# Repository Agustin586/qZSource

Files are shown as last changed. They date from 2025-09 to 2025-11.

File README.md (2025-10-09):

# ⚡ qZSource - Inversor Quasi Z-Source ⚡




## 🖼️ Vista del Proyecto

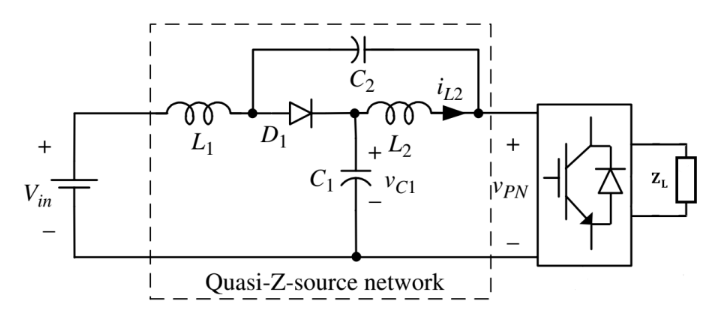
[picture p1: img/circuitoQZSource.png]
qZSource Inverter


> *Imagen del inversor Quasi Z-Source implementado*

## 📝 Descripción

Proyecto Final de Ingeniería Electrónica

Este proyecto implementa un **Inversor Quasi Z-Source (qZSI)** completo, incluyendo el diseño de hardware, firmware de control y simulaciones. El inversor qZSI es una topología avanzada que combina las funciones de elevación de tensión y inversión en una sola etapa, ofreciendo ventajas como inmunidad a cortocircuitos y mayor eficiencia.

## ⭐ Características Principales

- **Topología**: Quasi Z-Source Inverter
- **Control**: DSP TMS320F28335 de Texas Instruments
- **Tensión de entrada**: 300V DC (configurable)
- **Tensión de salida**: 300V AC pico (configurable)
- **Frecuencia de salida**: 50Hz senoidal
- **Protecciones**: Hardware y software configurables
- **Modos de operación**: Lazo abierto y cerrado

## 📁 Estructura del Proyecto

```
qZSource/
├── Esquematicos/          # Diseños de PCB y esquemáticos
├── Programa/              # Firmware para DSP TMS320F28335
├── Simulaciones/          # Modelos y simulaciones PLECS
└── README.md             # Este archivo
```

## 🛠️ Tecnologías Utilizadas

- **Hardware**: TMS320F28335 DSP, MOSFETs, Drivers de compuerta
- **Software**: Code Composer Studio, IQmath Library
- **Simulación**: PLECS Blockset, Matlab Simulink
- **Diseño PCB**: Altium Designer (presumiblemente)

## 👥 Autores del proyecto 2025
- **Fasolato, Alejandro**
- **Soso, Alvaro**
- **Zuliani, Agustin**

## 👥 Autores del proyecto 2024

- **Guido Cicconi**
- **Gustavo García** 
- **Juan Tinazzo**

## 📄 Licencia

Este proyecto está licenciado bajo la Licencia BSD de 3 Cláusulas. Ver los archivos de código fuente para más detalles.

## 📅 Año

> 2025 - Proyecto Final de Ingeniería Electrónica - Lazo de Control
> 
> 2024 - Proyecto Final de Ingeniería Electrónica - Proyecto Base

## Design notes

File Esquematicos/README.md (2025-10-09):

# 🔌 Esquemáticos - Hardware qZSI

Este directorio contiene todos los diseños de hardware para el Inversor Quasi Z-Source, incluyendo esquemáticos, layouts de PCB y documentación de diseño.

## 📦 Contenido

### 🧩 Módulos de Diseño

- **`ControlBoard/`**: 🧠 Placa de control principal con DSP TMS320F28335
- **`Design_AC_Output/`**: 🌊 Circuito de salida AC y filtros
- **`Design_DC_AC_Converter/`**: ⚡ Etapa inversora DC-AC principal
- **`Design_DC_Input/`**: 🔋 Circuito de entrada DC y red quasi Z-source
- **`Design_Drivers/`**: 🚗 Drivers de compuerta para MOSFETs
- **`Driver_MOSFET_DC_Input/`**: 🔌 Driver específico para MOSFETs de entrada
- **`MultiBoard/`**: 🏗️ Diseño integrado de múltiples placas
- **`Reformas/`**: 🔄 Modificaciones y actualizaciones del diseño

## 🏗️ Arquitectura del Hardware

### 🧠 Placa de Control (ControlBoard)
- **Procesador**: DSP TMS320F28335 de Texas Instruments
- **Interfaces**: 
  - 📊 Entradas analógicas para sensado de corriente y tensión
  - 🎛️ Salidas PWM para control de MOSFETs
  - 📡 Comunicación I2C para potenciómetros digitales
  - 🔍 Entradas digitales para protecciones
- **Alimentación**: 🔌 Fuentes aisladas para control y potencia

### ⚡ Etapa de Potencia

#### 🔋 Red Quasi Z-Source (Design_DC_Input)
- **Inductores**: 🧲 L1, L2 para almacenamiento de energía
- **Capacitores**: ⚡ C1, C2 para filtrado y elevación de tensión
- **Sensores**: 📏 Medición de corrientes y tensiones

#### 🔄 Puente Inversor (Design_DC_AC_Converter)
- **MOSFETs**: 🔌 Semiconductores de potencia para conmutación
- **Drivers**: 🚗 Circuitos de excitación aislados
- **Protecciones**: 🛡️ Detección de sobrecorriente y fallas

#### 🌊 Salida AC (Design_AC_Output)
- **Filtro**: 📊 Filtro LC para obtener forma de onda senoidal
- **Sensores**: 📏 Medición de tensión y corriente de salida
- **Protecciones**: 🛡️ Monitoreo de parámetros de salida

### 🚗 Drivers de Compuerta (Design_Drivers)
- **Aislamiento**: 🔒 Aislamiento galvánico entre control y potencia
- **Protecciones**: 
  - 🔍 Detección de desaturación (DESAT)
  - ⚡ Protección por sobrecorriente
  - 🌡️ Monitoreo de temperatura
- **Señalización**: 💡 LEDs indicadores y señales de estado

## 📊 Especificaciones Técnicas

### ⚡ Parámetros Eléctricos
- **Tensión de entrada**: 🔋 200-400V DC
- **Tensión de salida**: 🌊 220V AC RMS (311V pico)
- **Corriente máxima**: ⚡ Depende del diseño específico
- **Frecuencia de conmutación**: ⏱️ 10 kHz
- **Frecuencia de salida**: 🌊 50 Hz

### 🛡️ Protecciones Implementadas
- ⚡ Sobrecorriente en inductores L1, L2
- 🔋 Sobretensión en capacitores C1, C2
- 🌊 Sobrecorriente en la salida AC
- 🌡️ Protección térmica en drivers
- 🚨 Fallas de hardware (FAULT, READY, OC, OCP)

## 🛠️ Herramientas de Diseño

Los esquemáticos fueron diseñados utilizando herramientas profesionales de diseño de PCB (probablemente Altium Designer o similar).

## 🎯 Consideraciones de Diseño

### 🔒 Aislamiento
- 🔒 Aislamiento galvánico entre etapas de control y potencia
- 🚧 Barreras de aislamiento en drivers de compuerta
- 🔌 Fuentes de alimentación aisladas

### 📡 EMI/EMC
- 📐 Layout optimizado para minimizar interferencias
- 🌍 Planos de masa apropiados
- 🔍 Filtros de entrada y salida

### 🌡️ Térmico
- 🌡️ Disipadores para semiconductores de potencia
- 📊 Monitoreo de temperatura en puntos críticos
- 💨 Ventilación adecuada

## 🧩 Estructura Modular

El diseño está organizado de forma modular para facilitar:
- 🔬 Pruebas individuales de cada etapa
- 🔧 Mantenimiento y reparación
- 📈 Escalabilidad del sistema
- ♻️ Reutilización de módulos

## 📚 Documentación

Cada módulo incluye:
- 📋 Esquemáticos detallados
- 📊 Lista de materiales (BOM)
- 🔧 Consideraciones de montaje
- 🧪 Procedimientos de prueba

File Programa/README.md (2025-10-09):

# 💻 Programa - Firmware qZSI

Este directorio contiene el firmware completo para el control del Inversor Quasi Z-Source implementado en el DSP TMS320F28335 de Texas Instruments.

## 📦 Contenido

- **qZSI-Firmware/**: Proyecto completo de Code Composer Studio con todo el firmware del inversor

## 🏗️ Arquitectura del Firmware

El firmware está organizado en módulos funcionales para facilitar el mantenimiento y la escalabilidad:

### 🧠 Módulos Principales

#### `main.c` - Corazón del Sistema
- **Función principal**: Inicialización y loop principal del sistema
- **Configuración inicial**: Setup de todos los periféricos del DSP
- **Interrupciones**: Manejo de interrupciones de timer y ADC
- **Estado del sistema**: Control del estado global de la aplicación

#### `qZSI.c/h` - Motor de Control del Inversor
- **Algoritmos de control**: Implementación de los controladores PID
- **Cálculo de PWM**: Generación de ciclos de trabajo para MOSFETs
- **Protecciones**: Sistema de protecciones por software
- **Conversiones ADC**: Procesamiento de señales analógicas a valores físicos
- **Funciones clave**:
  - `qzsi_dcBusController()`: Control del bus DC con algoritmo no lineal
  - `qzsi_outputVoltageController()`: Control de tensión de salida con PID cascadeado
  - `qzsi_updatePWM()`: Actualización de registros PWM del DSP
  - `qzsi_getOpenLoop_d0()`: Cálculo de ciclo de trabajo en lazo abierto

#### `mefPrincipal.c/h` - Máquina de Estados Principal
- **Estados del sistema**: INICIO, RUN, FALLA, RESET_FALLA
- **Gestión de fallas**: Detección y manejo de condiciones de error
- **Secuencia de arranque**: Coordinación del arranque del sistema
- **Interfaz de usuario**: Manejo de botones y LEDs indicadores

#### `mefArranque.c/h` - Secuencia de Arranque Inteligente
- **Arranque progresivo**: Encendido suave del inversor
- **Carga de capacitores**: Precarga controlada de la red Z-source
- **Verificaciones**: Chequeos de seguridad antes del arranque
- **Transiciones**: Cambio gradual entre modos de operación

### 🔌 Drivers y Periféricos

- **`main.c`**: Función principal y configuración inicial del sistema
- **`qZSI.c/h`**: Algoritmos de control del inversor quasi Z-source
- **`mefPrincipal.c/h`**: Máquina de estados principal del sistema
- **`mefArranque.c/h`**: Máquina de estados de arranque secuencial

### Drivers y Periféricos

- **`Drivers/`**: Drivers para periféricos externos
  - `digitalPot.c/h`: Control de potenciómetros digitales MCP4461 vía I2C
  - `key.c/h`: Debounce y manejo de botones con detección de flancos
  - `LedIndicator.c/h`: Control de LEDs indicadores con códigos de error
  - `MCP4461.c/h`: Driver específico para potenciómetro digital de 4 canales

### ⚙️ Inicialización de Hardware

- **`Inits/`**: Módulos de inicialización críticos del DSP
  - `Adc.c/h`: ADC de 12 bits, 16 canales, conversión sincronizada con PWM
  - `EPwm.c/h`: 6 módulos PWM para control de MOSFETs y sincronización
  - `Gpio.c/h`: 88 pines GPIO para entradas/salidas digitales
  - `I2C.c/h`: Comunicación I2C a 400 kHz para potenciómetros
  - `SysCtrl.c/h`: PLL, relojes del sistema, configuración a 150MHz
  - `PieCtrl.c/h`: Controlador de interrupciones vectorizadas
  - `Watchdog.c/h`: Perro guardián para detección de bloqueos

### 🛠️ Utilidades y Algoritmos

- **`Utils/`**: Funciones auxiliares matemáticas
  - `ringBuffer.c/h`: Buffers circulares optimizados para filtros digitales IIR/FIR

## 🎯 Características Avanzadas del Control

### 🔄 Algoritmos de Control Implementados

1. **🔋 Control de Tensión DC Bus**: 
   - Algoritmo no lineal basado en modelo matemático
   - Controlador con ganancias variables según punto de operación
   - Compensación automática de variaciones de carga
   
2. **⚡ Control de Tensión de Salida**: 
   - PID cascadeado: tensión externa, corriente interna
   - Filtros digitales pasa-bajos para reducir ruido
   - Generación de referencia senoidal con tabla lookup
   
3. **🎛️ Generación PWM Avanzada**: 
   - 6 señales PWM sincronizadas
   - Tiempos muertos programables
   - Protección por hardware integrada
   
4. **🛡️ Sistema de Protecciones Multinivel**: 
   - Protecciones por hardware (instantáneas)
   - Protecciones por software (configurables)
   - Recuperación automática después de fallas

### ⚙️ Parámetros de Configuración Críticos

El archivo `inverterConfig.h` permite configurar múltiples aspectos:

#### 🎚️ Modos de Operación
- `SALIDA_SENOIDAL`: Habilita salida senoidal vs. continua
- `OUTPUT_VOLTAGE_CLOSED_LOOP`: Control en lazo cerrado de tensión
- `BUS_VOLTAGE_CLOSED_LOOP`: Control en lazo cerrado del bus DC

#### 🛡️ Sistemas de Protección
- `HARDWARE_PROTECTIONS`: Protecciones por hardware del DSP
- `SOFTWARE_PROTECTIONS`: Protecciones por software configurables

#### 📊 Referencias del Sistema
- `OPEN_LOOP_VIN`: Tensión de entrada nominal (300V)
- `DC_BUS_VOLTAGE_REFERENCE`: Tensión del bus DC objetivo (380V)
- `MAX_OUTPUT_VOLTAGE_REFERENCE`: Tensión de salida máxima (300V pico)

### 📚 Librerías Especializadas

- **🧮 IQmath**: Biblioteca de matemática de punto fijo de TI (Q15, Q24)
- **🎯 DSP2833x**: Drivers optimizados y definiciones para el DSP F28335
- **📋 Headers TI**: Archivos de cabecera estándar de Texas Instruments

## 🔧 Detalles Técnicos de Implementación

### ⏱️ Temporización y Sincronización

### 🔨 Herramientas Requeridas

El proyecto está configurado para **Code Composer Studio** y requiere:

1. **Code Composer Studio v6.0** o superior
2. **Compilador C2000** de Texas Instruments
3. **Biblioteca IQmath** instalada
4. **XDS100v2** o emulador compatible para debugging

### 📁 Configuración del Proyecto

#### 🎯 Target Configuration
- **Device**: TMS320F28335
- **Connection**: XDS100v2 USB Emulator
- **Gel Files**: Configuración de registros y memoria

#### 🔗 Linker Configuration
- **Flash**: Código de inicialización
- **RAM**: Código crítico de control
- **Sectores**: Optimizados para velocidad de ejecución

### 🏃‍♂️ Proceso de Build

```bash
# Compilación optimizada para velocidad
Optimization Level: -O2
# Punto fijo habilitado
IQmath Support: Enabled
# Debugging symbols
Debug Info: Full
```

## 🔍 Análisis de Rendimiento

### 📊 Uso de Memoria
- **Program Flash**: ~80KB de 256KB disponibles
- **Data RAM**: ~15KB de 34KB disponibles
- **Stack**: 1KB reservado para interrupciones

### ⚡ Timing Analysis
- **ISR de control**: ~25µs de ejecución
- **Conversión ADC**: ~2µs por canal
- **Cálculo PWM**: ~5µs para 6 canales
- **Margen disponible**: ~18µs por ciclo de control

## 🚀 Próximas Implementaciones

### 🎯 Mejoras Planificadas
- [ ] Control adaptativo de ganancia
- [ ] Estimador de parámetros en línea
- [ ] Comunicación CAN bus
- [ ] Interface gráfica de usuario
- [ ] Data logging en memoria externa

- **⏰ Frecuencia PWM**: 10 kHz (período de 100 µs)
- **📊 Frecuencia de muestreo ADC**: 20 kHz (2 muestras por período PWM)
- **🌊 Frecuencia de salida**: 50 Hz (senoidal de red)
- **🔄 Loop de control**: Ejecutado cada 50 µs (sincronizado con PWM)

### 🧠 Optimizaciones de Rendimiento

#### 💾 Gestión de Memoria
- **Código crítico en RAM**: Rutinas de control para máxima velocidad
- **Datos en SARAM**: Variables de control en memoria rápida
- **Stack optimizado**: Configurado para manejar interrupciones anidadas

#### ⚡ Optimizaciones de Código
- **IQmath**: Aritmética de punto fijo para cálculos rápidos
- **Inline functions**: Funciones críticas declaradas como inline
- **Loop unrolling**: Desenrollado de bucles en filtros digitales

### 🔍 Sistema de Debugging

#### 📊 Variables de Monitoreo
- Variables globales visibles en debugger
- Buffers de datos para análisis en tiempo real
- Contadores de rendimiento y estadísticas

#### 🚨 Códigos de Error
- Sistema de LEDs con códigos específicos
- Registro de fallas con timestamp
- Recuperación automática o manual según tipo de error

## 🛠️ Compilación y Desarrollo

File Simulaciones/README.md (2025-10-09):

# 📊 Simulaciones - Modelado qZSI

Este directorio contiene las simulaciones y modelos matemáticos del Inversor Quasi Z-Source desarrollados para validar el diseño y optimizar los algoritmos de control.

## 📦 Contenido

- **`simulacion/`**: 🔬 Modelos de simulación y archivos de proyecto
- **`licencia/`**: 📄 Archivos de licencia del software PLECS

## 🛠️ Herramienta de Simulación

### 📊 PLECS (Piecewise Linear Electrical Circuit Simulation)

- **Software**: 📊 PLECS Blockset para MATLAB/Simulink
- **Versión**: 🎓 Licencia estudiantil 2022
- **Fabricante**: 🏢 Plexim GmbH

### 📄 Archivos de Licencia

El directorio `licencia/` contiene:
- 📄 `license.lic`: Archivo de licencia PLECS
- 📋 `General_Terms_and_Conditions_Plexim_2018.pdf`: Términos y condiciones generales
- 🎓 `PLECS_Student_Licensing_Terms_and_Conditions_11_2022.pdf`: Términos específicos de licencia estudiantil

## 🔬 Modelos Implementados

### 🏗️ Modelo Completo del Sistema

El modelo de simulación incluye:

#### 🔋 Red Quasi Z-Source
- **Inductores L1, L2**: 🧲 Modelado con resistencias parásitas
- **Capacitores C1, C2**: ⚡ Modelado con ESR (resistencia serie equivalente)
- **Comportamiento dinámico**: 📊 Respuesta transitoria y en estado estacionario

#### 🔄 Puente Inversor
- **MOSFETs**: 🔌 Modelo de conmutación ideal con pérdidas configurables
- **Drivers**: 🚗 Retardos y limitaciones de slew rate
- **Dead-time**: ⏱️ Tiempo muerto entre conmutaciones

#### 🧠 Control Digital
- **DSP**: 💻 Modelado de los algoritmos de control implementados
- **PWM**: 🎛️ Generación de señales moduladas
- **ADC**: 📊 Muestreo y cuantización de señales analógicas

#### 🌊 Filtro de Salida
- **Filtro LC**: 📈 Filtrado de armónicos de conmutación
- **Carga**: 🔌 Diferentes tipos de carga (resistiva, RL, no lineal)

### 🎯 Algoritmos de Control Simulados

#### 🔓 Control de Lazo Abierto
- 🎚️ Cálculo de ciclo de trabajo `d0` para shoot-through
- 🎛️ Cálculo de ciclo de trabajo `d` para vector activo
- 🌊 Generación de referencia senoidal

#### 🔒 Control de Lazo Cerrado
- **PID de Corriente**: ⚡ Control de corriente de inductor
- **PID de Tensión**: 🌊 Control de tensión de salida
- **Filtros Digitales**: 📊 Filtros pasa-bajos para mediciones

### 🛡️ Protecciones Simuladas
- ⚡ Límites de corriente en inductores
- 🔋 Límites de tensión en capacitores
- 🌊 Protección por sobrecorriente de salida
- 🚨 Detección de fallas de hardware

## 📋 Casos de Estudio

### 🔬 Análisis Realizados

1. **🚀 Arranque del Sistema**
   - ⚡ Secuencia de encendido progresivo
   - 🔋 Carga de capacitores de la red Z
   - 📊 Establización de tensiones

2. **📈 Respuesta ante Escalones**
   - 🔌 Cambios en la carga
   - 🔋 Variaciones de tensión de entrada
   - 🎯 Cambios en referencias

3. **🔍 Análisis de Estabilidad**
   - 📊 Márgenes de fase y ganancia
   - 📈 Respuesta en frecuencia
   - 🛡️ Robustez del control

4. **⚡ Eficiencia Energética**
   - 🔄 Pérdidas de conmutación
   - 🔌 Pérdidas de conducción
   - 📊 Eficiencia total del sistema

### ✅ Validación de Diseño

Las simulaciones se utilizaron para:

- **🧮 Dimensionamiento de componentes**: L, C, MOSFETs
- **🎛️ Ajuste de controladores**: Parámetros PID
- **🛡️ Verificación de protecciones**: Umbrales y tiempos
- **📈 Optimización de rendimiento**: THD, eficiencia

## ⚙️ Parámetros de Simulación

### 📊 Condiciones Nominales
- **Tensión de entrada**: 🔋 300V DC
- **Tensión de salida**: 🌊 220V AC RMS
- **Frecuencia de salida**: 📊 50 Hz
- **Frecuencia de conmutación**: ⏱️ 10 kHz
- **Carga nominal**: 🔌 Resistiva, RL

### 🧲 Componentes de la Red Z
- **L1 = L2**: 🧲 3.2 mH
- **C1 = C2**: ⚡ 500 µF
- **Frecuencia de resonancia**: 🎯 Optimizada para la aplicación

## 📊 Resultados y Validación

### 📈 Métricas Evaluadas
- **THD (Total Harmonic Distortion)**: 📊 Distorsión armónica total < 5%
- **Eficiencia**: ⚡ > 90% en condiciones nominales
- **Regulación de tensión**: 📈 ±2% para variaciones de carga
- **Factor de potencia**: 🎯 > 0.95 con carga resistiva

### 🔬 Comparación con Resultados Experimentales
- ✅ Validación de formas de onda
- ⚡ Verificación de eficiencia
- 🛡️ Confirmación de estabilidad

## 💻 Software Requerido

Para ejecutar las simulaciones:
- 📊 MATLAB R2020b o superior
- 🔧 Simulink
- 📈 PLECS Blockset (licencia válida)
- 🧠 Conocimientos básicos de electrónica de potencia

## 📁 Archivos de Salida

Las simulaciones generan:
- 📊 Formas de onda de tensiones y corrientes
- 📈 Análisis espectral (FFT)
- ⚡ Gráficos de eficiencia
- 📋 Reportes de THD
- ✅ Datos para validación experimental

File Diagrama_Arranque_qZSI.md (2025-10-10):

# 🔄 Diagrama de Flujo - Arranque del Convertidor qZSI

## 📊 Flujo Principal de Arranque

```mermaid
graph TD
    A[🔌 POWER ON] --> B[⚙️ INICIALIZACIÓN SISTEMA]
    B --> C[🛡️ VERIFICACIÓN HARDWARE]
    C --> D{🔍 Hardware OK?}
    
    D -->|❌ NO| E[🚨 ESTADO FALLA]
    D -->|✅ SÍ| F[🚀 INICIO ARRANQUE]
    
    F --> G[⏱️ Esperar 5s]
    G --> H[🔌 SW_IN = 1<br/>Conectar entrada resistiva]
    
    H --> I[⏱️ Esperar 10s<br/>Carga suave capacitores]
    I --> J[⚡ VSEL = 1<br/>Entrada directa]
    
    J --> K[🔋 Habilitar salida]
    K --> L[📈 Aumentar VBUS<br/>Objetivo: 380V]
    
    L --> M{🎯 VBUS = 380V?}
    M -->|❌ NO| L
    M -->|✅ SÍ| N[✅ VBUS Enganchado]
    
    N --> O[⏱️ Esperar 5s]
    O --> P[🌊 Aumentar VO<br/>Objetivo: 300V]
    
    P --> Q{🎯 VO = 300V?}
    Q -->|❌ NO| P
    Q -->|✅ SÍ| R[✅ VO Enganchado]
    
    R --> S[⏱️ Esperar 5s]
    S --> T[🟢 FUNCIONAMIENTO NORMAL]
    
    E --> U[💡 LED Código Error]
    E --> V{🔧 Reset Manual?}
    V -->|❌ NO| E
    V -->|✅ SÍ| C
    
    T --> W{🚨 Falla?}
    W -->|❌ NO| T
    W -->|✅ SÍ| E
```

## 🏗️ Diagrama Detallado de Estados

```mermaid
stateDiagram-v2
    [*] --> POWER_ON : Sistema energizado
    
    POWER_ON --> INICIO : Inicialización hardware
    INICIO --> CLEAR_INICIAL : Timer 100ms
    
    CLEAR_INICIAL --> RUN : Hardware Ready
    CLEAR_INICIAL --> WAIT_HW_READY : Hardware NOT Ready
    
    RUN --> INICIO_ARRANQUE : Ejecutar MEF Arranque
    
    state RUN {
        INICIO_ARRANQUE --> SW_IN_RESISTIVO : 5s delay
        SW_IN_RESISTIVO --> AUMENTANDO_VBUS : 10s delay + VSEL=1
        AUMENTANDO_VBUS --> CONTROLADOR_VBUS_ENGANCHADO : VBUS = 380V
        CONTROLADOR_VBUS_ENGANCHADO --> AUMENTANDO_VO : 5s delay
        AUMENTANDO_VO --> CONTROLADOR_VO_ENGANCHADO : VO = 300V  
        CONTROLADOR_VO_ENGANCHADO --> RUN_NORMAL : 5s delay
        RUN_NORMAL --> RUN_NORMAL : Operación continua
    }
    
    RUN --> FALLA : Error detectado
    FALLA --> REST_FALLA : Button CLR_FAULT
    REST_FALLA --> WAIT_HW_READY : 100ms delay
    WAIT_HW_READY --> RUN : Hardware Ready
    
    FALLA --> FALLA : Sin acción usuario
```

## ⚙️ Secuencia de Señales de Control

```mermaid
gantt
    title Secuencia Temporal de Arranque qZSI
    dateFormat X
    axisFormat %s
    
    section Hardware Init
    Reset Drivers    :done, reset, 0, 100ms
    Enable Level Shifters :done, enable, 0, 100ms
    
    section Arranque Suave
    SW_IN = 0 (Resistivo)  :active, sw0, 0, 5000ms
    SW_IN = 1 (Directo)    :sw1, after sw0, 10000ms
    VSEL = 1 (Bypass)      :vsel, 5000ms, 10000ms
    
    section Control VBUS
    Habilitar Salida       :vo_enable, 15000ms, 100ms
    Rampa VBUS 0→380V      :vbus_ramp, after vo_enable, 3000ms
    VBUS Estabilizado      :vbus_stable, after vbus_ramp, 5000ms
    
    section Control VO
    Clear Vo Inicial       :vo_clear, after vbus_stable, 100ms
    Rampa VO 0→300V        :vo_ramp, after vo_clear, 2000ms
    VO Estabilizado        :vo_stable, after vo_ramp, 5000ms
    
    section Operación
    Funcionamiento Normal  :normal, after vo_stable, 10000ms
```

## 📋 Descripción de Cada Etapa

### 🔧 **1. INICIALIZACIÓN (0-100ms)**
- Reset de drivers de compuerta
- Habilitación de level shifters
- Configuración inicial de periféricos
- Verificación de protecciones hardware

### 🔌 **2. ENTRADA RESISTIVA (5s)**
- `SW_IN = 0`: Conexión a través de resistor limitador
- Carga controlada de capacitores de entrada
- Protección contra corrientes de irrupción

### ⚡ **3. ENTRADA DIRECTA (10s)**
- `SW_IN = 1`: Bypass del resistor limitador
- `VSEL = 1`: Conexión directa a fuente
- Estabilización de tensión de entrada

### 🔋 **4. CONTROL VBUS (Variable)**
- Habilitación de salida PWM
- Rampa gradual de VBUS: 0V → 380V
- Control de lazo abierto inicial
- Verificación de alcance de referencia

### 🌊 **5. CONTROL VO (Variable)**
- Liberación de restricción de Vo inicial
- Rampa gradual de VO: 0V → 300V
- Transición a control normal
- Verificación de alcance de referencia

### 🟢 **6. FUNCIONAMIENTO NORMAL**
- Control automático de VBUS y VO
- Monitoreo continuo de protecciones
- Operación estable del inversor

## 🛡️ Protecciones Durante el Arranque

### Hardware
- Trip Zone activo en todo momento
- Monitoreo de sobrecorriente instantáneo
- Protección térmica de drivers

### Software
- Verificación de límites de tensión/corriente
- Timeouts en cada etapa
- Recuperación automática ante fallas menores

## ⏱️ Tiempos Típicos de Arranque

| Etapa | Tiempo | Descripción |
|---|---|---|
| Inicialización | 100ms | Setup hardware |
| Entrada Resistiva | 5s | Carga suave |
| Entrada Directa | 10s | Estabilización |
| Rampa VBUS | 2-5s | Dependiente de carga |
| Rampa VO | 1-3s | Control progresivo |
| **TOTAL** | **~20s** | Arranque completo |

Este arranque gradual asegura que no haya transitorios bruscos que puedan dañar los componentes del sistema. 🚀

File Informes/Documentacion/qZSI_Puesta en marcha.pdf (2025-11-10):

# PUESTA EN MARCHA

# qZSI

2025

## Director: Vazquez Sieber, Andrés

## Autores:

Fasolato, Alejandro Claudio, Soso, Alvaro Francisco,
Zuliani, Agustín Marcelo,

## 1. Introduction

El inversor monofásico quasi-Z-source (qZSI) desarrollado en el marco del proyecto final de la carrera de Ingeniería Electrónica, a diferencia de un inversor convencional de fuente de tensión, la inclusión de la red quasi-Z permite elevar la tensión de bus a partir de una fuente de entrada reducida mediante la inserción controlada de intervalos de shoot-through. Esta característica le otorga un funcionamiento más versátil, aunque al mismo tiempo introduce riesgos de operación asociados a la presencia de tensiones elevadas, corrientes pulsantes y circuitos de protección que deben verificarse antes de cada ensayo.

Dada la complejidad del equipo, resulta imprescindible contar con un protocolo estandarizado de encendido, destinado a guiar paso a paso el proceso de energización y las verificaciones intermedias necesarias para garantizar seguridad de las personas, preservación del hardware y validez de las mediciones obtenidas.

## 2. Objetivo

El objetivo de este documento es establecer un procedimiento detallado y seguro para la puesta en marcha del inversor qZSI, abarcando desde la preparación previa hasta la energización progresiva y las verificaciones de funcionamiento. Este protocolo permitirá:

- Reducir riesgos de daño al equipo y al personal durante los ensayos.
- Asegurar que las condiciones de prueba sean reproducibles.
- Facilitar la puesta en marcha mediante protocolos y configuraciones rápidas.
- Validar que los módulos de protección, sensado y control operan correctamente antes de aplicar potencia nominal.

## 3. Tareas preliminares

## 3.1. Verificaciones sobre las placas

Continuidad de masas.
Continuidad entre conexiones. Valor de las tensiones de fuentes.

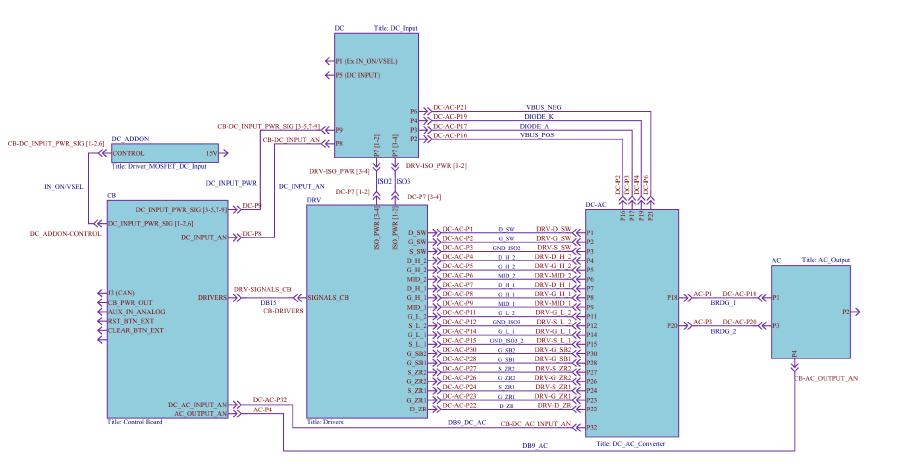
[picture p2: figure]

## 3.2. Conexionado externo

Conexión de la entrada CC del tablero a fuente de CC.
Conexión de la salida CA del convertidor al Tablero de Seguridad. Conexión del Tablero de Seguridad a la alimentación auxiliar. Conexión de salida CA del Tablero de Seguridad a la carga.

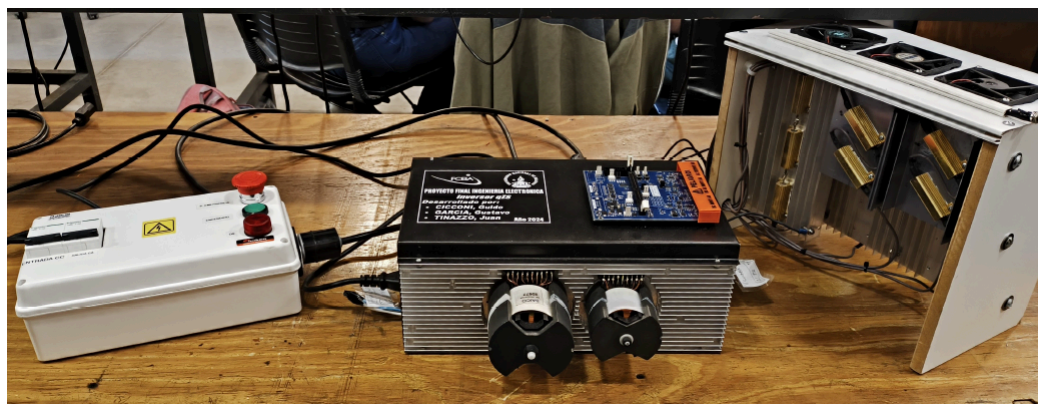
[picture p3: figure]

## 4. Firmware

## 4.1. Secuencia de arranque

4.1.1. Estados de la MEF
- RESET-INICIO: Inicialización de periféricos, colocar salidas en bajo.

Coloca la bandera de falla en cero.
PWM deshabilitado, inhabilita etapa entrada a drivers.
Limpia flag del flip flop de protecciones.
Habilita la salida de los level shifters.
Verificar que los drivers estén apagados con sus respectivas salidas.

TRANSICIONES

➔ Se detecta algún fault activo (UV, OV, OCP, emergencia) >> FAULT ➔ Aguarda 100ms, y si fault inactivo >> CLEAR

- CLEAR_INICIAL: Resetea drivers y flip flop.

Lee falla del driver.
Lee falla en sensor de corriente AC de efecto Hall. Lee falla de hardware del GPIO.

MEDICIONES

❖ De existir errores, puede medirse sobre la placa con un multímetro los distintos estados de reset y fallas antes mencionados.

TRANSICIONES

➔ Error de inicialización, lectura inválida o tensión fuera de rango.>> FAULT
➔ Si no hay falla, todos los periféricos fueron inicializados correctamente y la calibración del ADC fue completada >> INICIO - ARRANQUE

- INICIO_ARRANQUE: Se prepara para la carga del bus.

Se colocan banderas V0 y VB de arranque. Asegura MOS de la entrada abierto. Secuencia ‘1’ de Leds.
LED 2 = 0
LED 3 = 0
LED 4 = 1
Coloca las referencias de V0 y VB en 0.

MEDICIONES

❖ Medir que la tensión VBUS = 0 (durante 5 seg).

TRANSICIONES

➔ Transcurridos 5 segundos >> CARGA

- SW_IN_RESISTIVO: Carga de la red Z durante 10s.

Se habilita “resistencia” de precarga para cargar capacitores del bus lentamente.
- Si VBUS no sube, posible corto en bus o snubber → cortar y medir resistencia en bus.
Secuencia ‘2’ de Leds.
LED 2 = 0
LED 3 = 1
LED 4 = 0

MEDICIONES

❖ Medir VGS del Mosfet para ver la variación de su tensión.
❖ Medir la VBUS para observar su aumento y corroborar con los datos de la simulación.
❖ Medir forma de corriente de IL1 + IL2, Io. Corroborar con la simulación.

TRANSICIONES

➔ Activación de protección por hardware (OCP, OV, UV). >> FAULT ➔ Tiempo de precarga 10 segundos transcurrido >> AUMENTA VB

- AUMENTANDO_VBUS: Transición a LA desde Vin a Vb*.

MOSFET de entrada se polariza como llave cerrada.
Enciende salida senoidal con D máx = 0,45.
Setea referencia de VBUS y coloca d0 a lazo abierto, esperando que VBUS incremente.
Secuencia ‘3’ de LEDs.
LED 2 = 0
LED 3 = 1
LED 4 = 1

MEDICIONES

❖ VBUS
❖ Corrientes
- IL1 + IL2
- Io

TRANSICIONES

➔ Activación de protección por hardware (OCP, OV, UV). >> FAULT
➔ Elevación de Vb=Vb* >> CONTROL VB ONLINE
- CONTROLADOR_VBUS_ENGANCHADO: Valor de d0 comandado por Control.

Baja la bandera de Vb arranque, logrando así enganchar el control de tensión de bus. Se comenzará a utilizar d0 proveniente del algoritmo de control.
Secuencia ‘4’ de Leds:
LED 2 = 1
LED 3 = 0
LED 4 = 0

Durante este tiempo valen las siguientes funciones para calcular los ciclos de trabajo:
- d0 = (VBUS - Vin) / (2*VBUS)
- D = Vo/VBUS * sin(wt)

MEDICIONES

❖ VBUS

TRANSICIONES

➔ Activación de protección por hardware (OCP, OV, UV). >> FAULT ➔ Tiempo de enganche de 5 segundos >> CONTROL VB ONLINE VB

- AUMENTA_V0: Transición a LA desde Vo_inicial a Vo*

Setea V0* y coloca un D a lazo abierto, esperando que V0 incremente. Secuencia ‘5’ de Leds:
LED 2 = 1
LED 3 = 1
LED 4 = 0

MEDICIONES

❖ Vout

TRANSICIONES

➔ Activación de protección por hardware (OCP, OV, UV). >> FAULT
➔ Elevación de V0=V0* >> CONTROL V0 ONLINE
- CONTROLADOR_V0_ENGANCHADO: Valor de D comandado por Control.

Baja la bandera de V0 arranque, logrando así enganchar el control de tensión de salida. Se comenzará a utilizar D proveniente del algoritmo de control. arranqueV0 = 0 → D se controla por el Lazo cerrado/abierto

MEDICIONES

❖ Vout

TRANSICIONES

➔ Activación de protección por hardware (OCP, OV, UV). >> FAULT ➔ Tiempo de enganche de 5 segundos >> RUN

- RUN

LED de estado en RUN.

- Si VBUS se dispara, puede deberse a su controlador saturado. Además: Posible desconexión de la carga.
- Si la corriente de entrada es anómala, revisar inductores/cargas.

TRANSICIONES

➔ Se detecta OCP, OV, UV, sobretemperatura o error de firmware. >> FAULT ➔ Se recibe comando de parada o fin de ensayo. >> INICIO

- FAULT: Aislar el inversor, guardar log de error y esperar intervención.

Setea bandera de falla.
Requiere reset manual. Borra la bandera de falla, reinicia periféricos LED estado falla.

MEDICIONES

❖ Flip Flop seteado

TRANSICIONES

➔ Se ejecuta reset manual >> RESET FALLA

### Condiciones que disparan FAULT

➔ Protección por hardware activada:
◆ | OCP: corriente > umbral de comparador analógico.
◆ | OVP: tensión de bus o snubber > límite.
◆ | UVP: tensión de alimentación fuera de rango.
◆ | OTP: sobretemperatura en drivers o control.
➔ Comando manual (pulsador de emergencia).
➔ Error de firmware detectado (ADC out-of-range, ISR colgada, watchdog).

- RES FALLA

Apaga la etapa de entrada de los drivers.

TRANSICIONES

➔ Tiempo de apagado 100ms >> WAIT HW READY.

- WAIT HW READY

Reseta drivers y sensor efecto hall.
Resetea tripzone.
Baja la bandera de falla.

MEDICIONES

❖ Drv reseteados
❖ Tripzone reseteado

TRANSICIONES

➔ Hardware ready >> INICIO ARRANQUE.

## 4.2. Configuraciones FIRMWARE

4.2.1. Archivo inverterConfig.h

En este archivo se puede configurar el funcionamiento general del inversor, activando o desactivando distintos bloques que lo componen, y seteando las tensiones de referencia deseadas.Las macros disponibles son:

- SALIDA_SENOIDAL: si vale 1, la salida del inversor será senoidal, en caso contrario, será una tensión continua. Es una macro útil para testear el funcionamiento en las etapas iniciales.
- HARDWARE_PROTECTIONS: si vale 1, las protecciones por hardware del inversor están activadas, en caso contrario, estarán desactivadas. Es útil si por alguna razón se producen disparos espurios de las protecciones por hardware y se quiere investigar su origen.
- SOFTWARE_PROTECTIONS: análoga a la anterior, permite activar o desactivar las protecciones por software del inversor.
- OUTPUT_VOLTAGE_CLOSED_LOOP: si vale 1, la tensión senoidal de salida del inversor funciona a lazo cerrado, en caso contrario, a lazo abierto. Es útil a la hora de probar el funcionamiento del controlador de salida implementado.
- BUS_VOLTAGE_CLOSED_LOOP: análoga a la anterior, permite activar o desactivar el lazo de control de la tensión del bus de CC.
- OPEN_LOOP_VIN: es el valor de la tensión de entrada al momento del arranque del inversor, ya que se utiliza para generar la tensión del bus de CC a lazo abierto.
- DC_BUS_VOLTAGE_REFERENCE: es el valor de referencia deseado para la tensión del bus de CC.
- MAX_OUTPUT_VOLTAGE_REFERENCE: es el valor de referencia deseado para la tensión de salida del inversor, siendo este el valor de pico y no el RMS

4.2.2. Archivo qZSI.h

En este archivo se puede configurar el comportamiento dinámico, la tensión de salida inicial en el arranque y los valores de protección por software del inversor. Las macros disponibles son:

- STEP_TIME_MS: es el tiempo de delay deseado entre pasos de un setpoint, ya que todo cambio de setpoint se realiza de forma gradual, de a una unidad cada STEP_TIME_MS milisegundos. Por ejemplo, si STEP_TIME_MS = 50, el set-point deseado del bus de CC está seteado en 100V y el mismo se cambia a 200V, este irá incrementando de a 1V cada 50ms, llegando a 200V en 5s. En caso de requerir que la rampa de subida sea más rápida, se puede reducir el tiempo del escalón, pero el aumento de tensión seguirá siendo siempre de 1V por paso.
- INITIAL_D: es el valor deseado del ciclo de trabajo máximo del vector activo presente en la etapa 3 de la secuencia de arranque descrita anteriormente.
- DC_BUS_XI: es el valor de la constante de amortiguamiento ξ del sistema de segundo orden formado por la red Z y el controlador del bus de CC.
- DC_BUS_WN: es el valor de la frecuencia natural ωn del sistema de segundo orden formado por la red Z y el controlador del bus de CC. Estas últimas dos macros permiten configurar el comportamiento dinámico de la tensión del bus de CC.
- MAX_IL1, MIN_IL1, MAX_Iin, MAX_VC1, MAX_Vac, MAX_Iac, MIN_Iac: son los valores de umbral de las protecciones por software. Si la respectiva variable medida supera a sus valores de umbral, se activará la protección por software (en caso de que esté habilitada).
4.2.3. Archivo digitalPot.h

Mediante las macros VREF_IACm, VREF_IACp, VREF_VC12, VREF_Iin, VREF_IL1m, VREF_IL1p, VREF_IBRDGm, VREF_IBRDGp es posible configurar las tensiones de referencia utilizadas en los comparadores que accionan las protecciones por hardware. Gracias a la utilización de potenciómetros digitales, que se comunican con el DSP mediante el protocolo I2C, es posible configurar en el firmware los valores de referencia para la comparación. Estas macros mencionadas deben ser iguales al valor de tensión de referencia (en Voltios) deseado para cada caso. Al inicio del programa, se configuran los potenciómetros a partir de los valores seteados en estas macros. Aquellas macros cuyos nombres difieran en la última letra, siendo esta p o m, configuran la tensión de referencia para la misma señal, pero en el caso de p es la tensión de umbral máxima y en el de m, la tensión de umbral mínima.

## 5. Configuraciones externas

## 5.1. Fuente

Encadenar los canales de la fuente y encender la fuente Configurar las tensiones de salida …
Configurar la limitación de corriente
Medir en bornes la tensión y verificar que coincida con la deseada.

## 5.2. Carga

Ajustar o interconectar la carga en el valor deseado.
Medir en bornes y verificar el valor.
Si se utilizará escalón de carga, configurar el generador de onda para realizar la conmutación el rele y verificar el correcto funcionamiento.

## 5.3. Instrumental

5.3.1. Osciloscopio

Encender el equipo y ajustar los canales en el rango de medición esperado
Configurar cursores…
Configurar….
Verificar los canales y sus configuraciones con un generador de onda
5.3.2. Sondas diferenciales

Alimentar las sondas y configurar para la medición deseada verificar sus canales con el generador de onda.

5.3.3. Multimetro

Ajustar al rango y tipo de medición deseada.

## 6. Protocolo de encendido

## 6.1. Configuraciones

Configurar los instrumentos de medición, fuentes y cargas de manera adecuada, según lo requerido por el ensayo.

Verificar que la fuente de alimentación programable funcione correctamente; medir en vacío con multímetro que entregue la tensión seteada. Y limitación de corriente activada.
Conectar el banco RC a la salida de la fuente para suavizar la corriente de entrada. Revisar que las térmicas estén abiertas y que el pulsador de emergencia (“golpe de puño”) no esté accionado.
Medir la resistencia de carga y comprobar que coincide con el valor esperado.
Montar la protección plástica sobre la placa de control para evitar contacto con alta tensión.

## 6.1.1. Configuración de firmware

Programar el DSP C2000 con el código de control.
Verificar configuración inicial de PWM y ADC (sin aplicar tensión de potencia). Verificar que el firmware a cargar en el DSP sea el correcto, y que todos los parámetros sean acordes a lo configurado en el instrumental.
Verificar además la conexión entre la Control Board y la Docking Station.
Poner las variables que necesitamos ver en el código para ver que funcione como corresponde y ver la evolución.

## 6.2. Conexiones seguras

Realizar y verificar que todas las conexiones eléctricas sean correctas de acuerdo al ensayo a realizar.

Conexión de la entrada CC a fuente de CC.
Conexión de la salida CA del convertidor al Tablero de Seguridad.
Conexión del Tablero de Seguridad a la alimentación auxiliar.
Conexión de salida CA del Tablero de Seguridad a la carga.
Colocar las sondas de osciloscopio en los puntos de medición definidos y configurar escalas adecuadas.

Verificar que no haya cables sueltos.
Acomodarse en los puestos designados:

En caso de ser dos personas: una será la encargada de la alimentación del inversor y de tomar nota, mientras que otra realizará la carga del código y manejará el osciloscopio.
En caso de ser tres personas: una será la encargada de la alimentación del inversor,otra tomará nota y manejará el osciloscopio, mientras que otra cargará el código.

Confirmar que todos los participantes estén listos.

## 6.3. Alimentación

Verificar que el tablero de control esté alimentado.
Dar aviso de que se está por energizar el equipo.
Activar la salida de la fuente de tensión.
Cerrar la térmica principal y aplicar tensión de entrada desde la fuente programable.
Verificar que el inversor esté alimentado correctamente, midiendo las tensiones auxiliares del mismo generadas por su fuente flyback interna

## 6.4. Carga del código

Usar la “prueba segura” recomendada:

VIN ≈ 30 V → VBUS ≈ 50 V → VO ≈ 30 V

Esperar a que el inversor finalice su secuencia de arranque, condición indicada cuando su LED de estado deja de titilar y queda encendido todo el tiempo. Confirmar que la forma de onda de salida es la esperada a baja potencia con carga inicial de 180 Ω para 10W de potencia.

## 6.5. Escalado de potencia

Incrementar gradualmente la tensión de entrada y la potencia entregada. Tras cada incremento, verificar tensiones, corrientes y forma de onda.

Si aparece algún fenómeno extraño (picos, ruidos, oscilaciones), cortar inmediatamente con el golpe de puño.

## 6.6. Desenergización segura

Reducir la tensión de la fuente a 0 V.
Abrir térmica principal.
Desenergizar alimentación auxiliar.
Descargar capacitores de bus (verificar caída de tensión).
Guardar los logs de osciloscopio/mediciones para análisis posterior.
Al cabo de 3 minutos notificar a todos que es seguro manipular el equipo.

## 7. Procedimiento en caso de falla – Inversor qZSI

## 7.1. Detección inmediata

Picos de tensión/corriente inesperados.
Forma de onda distorsionada o fuera de rango. Ruidos inusuales (golpes eléctricos).
LEDs de protección encendidos o alarma en firmware.

Acción inmediata: cortar energía desde el pulsador de emergencia (“golpe de puño”) o apagar la fuente programable.

## 7.2. Parada segura

Abrir térmicas principales.
Bajar a cero la consigna de la fuente programable.
Verificar que los capacitores del bus DC se descarguen (tensión < 10 V), 3 min. Retirar alimentación auxiliar del sistema de control.

## 7.3. Aislamiento y diagnóstico inicial

Identificar en qué condición ocurrió la falla:

Encendido inicial / baja potencia / potencia nominal. Escalón de carga o cambio de consigna o de alimentación.

Anotar variables relevantes en ese instante:

VIN, VBUS, IO, corriente de entrada, duty aplicado.
Revisar registro en osciloscopio o logs de DSP si estaban activos.

## 7.4. Inspección del hardware

Buscar signos de daño (humo, olor, componentes oscurecidos).
Revisar cables flojos o conectores sueltos.
Medir continuidad/resistencia de inductores, MOSFETs, snubbers y drivers antes de reencender.
Verificar fusibles y TVS de protección.

## 7.5. Plan de Rearme

Si la falla fue leve (ej. saturación de consigna o medición fuera de escala):

Repetir ensayo en la configuración de “prueba segura” (VIN ≈ 30 V, VBUS ≈ 50 V). Confirmar que señales recuperaron los valores esperados.

Si persiste el problema:

Documentar síntomas.
No reintentar hasta revisar detalladamente el circuito afectado.

## 7.6. Registro obligatorio

Documentar fecha, condición de prueba, síntoma y acción tomada.
Guardar capturas de osciloscopio/telemetría.
Registrar si hubo intervención de protecciones hardware (OCP, OV, UV, snubber).

Nunca subir potencia nuevamente después de una falla sin antes hacer la “prueba segura” a baja tensión. Esto protege al equipo y confirma si el problema fue transitorio o persiste.

## 8. Matriz de diagnóstico

Síntoma | Posibles causas | Prueba rápida | Acción
vbus no sube / cae al cargar | ST deshabilitado, d0 saturado bajo, precarga activa | Log de d0 medir caída en precharge | Habilitar ST, revisar consigna Vbus,refVbus, bypass precharge
Rizado vbus alto a 2f | Baja carga, ESR bajo, control rápido | Medir carga | Aumentar Carga or ESR, bajar ωn del lazo (con margen)
Sobrepico al escalón de carga o fuente o referencia | ξ bajo, retardo de muestreo, | registro d0 | Subir ξ
d0 cerca de 0.5 | Exigencia de boost alta, Vin bajo | Medir Vin y carga | Reducir salida o aumentar Vin; proteger d0 máx
Corriente de diodo negativa (DCM) | Carga liviana | Medir iDi e iPN | Forzar CCM incrementando al carga
Medidas ruidosas/saturadas | Escala ADC/divisores, SNR, offset | Revisar ADC | Re-escalar, filtro digital, offset y calibración

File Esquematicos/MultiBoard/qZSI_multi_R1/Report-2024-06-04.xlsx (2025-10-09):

ID | Net Name | Pin | Module Net | Pin | Module Net
Connection Name: Wire (D_SW)
W1 | NetC14_1 | No Pin | No net | No Pin | No net
Connection Name: Wire (G_SW)
W1 | NetP2_1 | No Pin | No net | No Pin | No net
Connection Name: Wire (GND_ISO2)
W1 | NetC7_3 | No Pin | No net | No Pin | No net
Connection Name: Wire (D_H_2)
W1 | NetC7_1 | No Pin | No net | No Pin | No net
Connection Name: Wire (G_H_2)
W1 | NetP5_1 | No Pin | No net | No Pin | No net
Connection Name: Wire (D_H_1)
W1 | NetC7_1 | No Pin | No net | No Pin | No net
Connection Name: Wire (G_H_1)
W1 | NetP8_1 | No Pin | No net | No Pin | No net
Connection Name: Wire (MID_1)
W1 | NetP9_1 | No Pin | No net | No Pin | No net
Connection Name: Wire (G_L_2)
W1 | NetP11_1 | No Pin | No net | No Pin | No net
Connection Name: Wire (G_L_1)
W1 | NetP14_1 | No Pin | No net | No Pin | No net
Connection Name: Wire (GND_ISO3_2)
W1 | SGND | No Pin | No net | No Pin | No net
Connection Name: Wire (G_SB2)
W1 | NetP30_1 | No Pin | No net | No Pin | No net
Connection Name: Wire (G_SB1)
W1 | NetP28_1 | No Pin | No net | No Pin | No net
Connection Name: Wire (S_ZR2)
W1 | NetP6_1 | No Pin | No net | No Pin | No net
Connection Name: Wire (G_ZR2)
W1 | NetP26_1 | No Pin | No net | No Pin | No net
Connection Name: Wire (S_ZR1)
W1 | NetP9_1 | No Pin | No net | No Pin | No net
Connection Name: Wire (G_ZR1)
W1 | NetP23_1 | No Pin | No net | No Pin | No net
Connection Name: Wire (D_ZR)
W1 | NetP22_1 | No Pin | No net | No Pin | No net
Connection Name: Wire (VBUS_POS)
W1 | VBUS_POS/NetC7_1 | DC-P2-1 | VBUS_POS | DC-AC-P16-1 | NetC7_1
Connection Name: Wire (DIODE_A)
W1 | DIODE_A/NetC7_3 | DC-P3-1 | DIODE_A | DC-AC-P17-1 | NetC7_3
Connection Name: Wire (DIODE_K)
W1 | DIODE_K/NetC14_1 | DC-P4-1 | DIODE_K | DC-AC-P19-1 | NetC14_1
Connection Name: Wire (VBUS_NEG)
W1 | NetP6_1/NetC14_3 | DC-P6-1 | NetP6_1 | DC-AC-P21-1 | NetC14_3
Connection Name: Wire (BRDG_1)
W1 | NetP9_1/NetL2_16 | DC-AC-P18-1 | NetP9_1 | AC-P1-1 | NetL2_16
Connection Name: Wire (BRDG_2)
W1 | NetP6_1/NetL2_11 | DC-AC-P20-1 | NetP6_1 | AC-P3-1 | NetL2_11
Connection Name: Wire (DB15)
W1 | DGND/GND_DRV_RAW | DRV-SIGNALS_CB-1 | DGND | CB-DRIVERS-1 | GND_DRV_RAW
W2 | +5V/5V_DRV_RAW | DRV-SIGNALS_CB-2 | +5V | CB-DRIVERS-2 | 5V_DRV_RAW
W3 | RST/RST_5V | DRV-SIGNALS_CB-3 | RST | CB-DRIVERS-3 | RST_5V
W4 | LS_2/LS_2_5V | DRV-SIGNALS_CB-4 | LS_2 | CB-DRIVERS-4 | LS_2_5V
W5 | IN_ZR1/ZR1_5V | DRV-SIGNALS_CB-5 | IN_ZR1 | CB-DRIVERS-5 | ZR1_5V
W6 | IN_ZR2/ZR2_5V | DRV-SIGNALS_CB-6 | IN_ZR2 | CB-DRIVERS-6 | ZR2_5V
W7 | SB1/SB1_5V | DRV-SIGNALS_CB-7 | SB1 | CB-DRIVERS-7 | SB1_5V
W8 | IN_FD/FD_5V | DRV-SIGNALS_CB-8 | IN_FD | CB-DRIVERS-8 | FD_5V
W9 | SB2/SB2_5V | DRV-SIGNALS_CB-9 | SB2 | CB-DRIVERS-9 | SB2_5V
W10 | HS_2/HS_2_5V | DRV-SIGNALS_CB-10 | HS_2 | CB-DRIVERS-10 | HS_2_5V
W11 | RDY/RDY_5V_RAW | DRV-SIGNALS_CB-11 | RDY | CB-DRIVERS-11 | RDY_5V_RAW
W12 | FLT/FLT_5V_RAW | DRV-SIGNALS_CB-12 | FLT | CB-DRIVERS-12 | FLT_5V_RAW
W13 | HS_1/HS_1_5V | DRV-SIGNALS_CB-13 | HS_1 | CB-DRIVERS-13 | HS_1_5V
W14 | LS_1/LS_1_5V | DRV-SIGNALS_CB-14 | LS_1 | CB-DRIVERS-14 | LS_1_5V
W15 | DGND/GND_DRV_RAW | DRV-SIGNALS_CB-15 | DGND | CB-DRIVERS-15 | GND_DRV_RAW
W16 | EARTH | DRV-SIGNALS_CB-MH1 | EARTH | CB-DRIVERS-MH1 | EARTH
W17 | EARTH | DRV-SIGNALS_CB-MH2 | EARTH | CB-DRIVERS-MH2 | EARTH
Connection Name: Wire (ISO3)
W1 | +15V_ISO3_RAW/+15V_ISO2 | DRV-ISO_PWR-1 | +15V_ISO3_RAW | DC-P7-4 | +15V_ISO2
W2 | GND_ISO3_RAW/-15V_ISO2 | DRV-ISO_PWR-2 | GND_ISO3_RAW | DC-P7-3 | -15V_ISO2
Connection Name: Wire (ISO2)
W1 | +15V_ISO2/+15V_ISO3 | DRV-ISO_PWR-3 | +15V_ISO2 | DC-P7-1 | +15V_ISO3
W2 | GND_ISO2/-15V_ISO3 | DRV-ISO_PWR-4 | GND_ISO2 | DC-P7-2 | -15V_ISO3
Connection Name: Wire (IN_ON/VSEL)
W1 | VSEL/DC_IN_SW_5V | DC_ADDON-CONTROL-1 | VSEL | CB-DC_INPUT_PWR_SIG-1 | DC_IN_SW_5V
W2 | DC_IN_SW/DGND_RAW | DC_ADDON-CONTROL-2 | DC_IN_SW | CB-DC_INPUT_PWR_SIG-2 | DGND_RAW
W3 | DGND/VSEL_1_5V | DC_ADDON-CONTROL-3 | DGND | CB-DC_INPUT_PWR_SIG-6 | VSEL_1_5V
Connection Name: Wire (DB9_DC_AC)
W1 | IBRDG+_sns/IBRDG+_sns_ | CB-DC_AC_INPUT_AN-6 | IBRDG+_sns | DC-AC-P32-1 | IBRDG+_sns_
W2 | IBRDG-_sns/IBRDG-_sns_ | CB-DC_AC_INPUT_AN-2 | IBRDG-_sns | DC-AC-P32-2 | IBRDG-_sns_
W3 | VC1_2_sns/VC1_2_sns_ | CB-DC_AC_INPUT_AN-9 | VC1_2_sns | DC-AC-P32-3 | VC1_2_sns_
W4 | VC1_sns/VC1_sns_ | CB-DC_AC_INPUT_AN-5 | VC1_sns | DC-AC-P32-4 | VC1_sns_
W5 | SGND | CB-DC_AC_INPUT_AN-1 | No net | DC-AC-P32-5 | SGND
Connection Name: Wire (DB9_AC)
W1 | VAC2_sns/VAC2_sns_ | CB-AC_OUTPUT_AN-1 | VAC2_sns | AC-P4-2 | VAC2_sns_
W2 | AC_OUTPUT_GND/SGND | CB-AC_OUTPUT_AN-2 | AC_OUTPUT_GND | AC-P4-3 | SGND
W3 | IAC_sns/IAC_sns_ | CB-AC_OUTPUT_AN-3 | IAC_sns | AC-P4-5 | IAC_sns_
W4 | IAC_ref_sns/REF_MOD_ | CB-AC_OUTPUT_AN-4 | IAC_ref_sns | AC-P4-8 | REF_MOD_
W5 | AC_OUTPUT_OC_5V/OC_ | CB-AC_OUTPUT_AN-5 | AC_OUTPUT_OC_5V | AC-P4-6 | OC_
W6 | VAC1_sns/VAC1_sns_ | CB-AC_OUTPUT_AN-6 | VAC1_sns | AC-P4-1 | VAC1_sns_
W7 | AC_OUTPUT_5V/5V | CB-AC_OUTPUT_AN-8 | AC_OUTPUT_5V | AC-P4-4 | 5V
W8 | AC_OUTPUT_RST_5V/OC_EN_ | CB-AC_OUTPUT_AN-9 | AC_OUTPUT_RST_5V | AC-P4-7 | OC_EN_
Connection Name: Wire (DC_INPUT_PWR)
W1 | DGND_RAW/15V_ISO3EXT_- | CB-DC_INPUT_PWR_SIG-7 | DGND_RAW | DC-P9-1 | 15V_ISO3EXT_-
W2 | +15V_RAW/15V_ISO3EXT_+ | CB-DC_INPUT_PWR_SIG-5 | +15V_RAW | DC-P9-2 | 15V_ISO3EXT_+
Connection Name: Wire (DC_INPUT_AN)
W1 | Vin_sns | CB-DC_INPUT_AN-1 | Vin_sns | DC-P8-1 | Vin_sns
W2 | Iin-_sns | CB-DC_INPUT_AN-7 | Iin-_sns | DC-P8-2 | Iin-_sns
W3 | Iin+_sns | CB-DC_INPUT_AN-3 | Iin+_sns | DC-P8-3 | Iin+_sns
W4 | IL1-_sns/Il1-_sns | CB-DC_INPUT_AN-9 | IL1-_sns | DC-P8-4 | Il1-_sns
W5 | IL1+_sns/Il1+_sns | CB-DC_INPUT_AN-5 | IL1+_sns | DC-P8-5 | Il1+_sns

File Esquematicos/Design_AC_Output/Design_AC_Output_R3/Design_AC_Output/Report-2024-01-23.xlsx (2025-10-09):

ID | Net Name | Pin | Module Net | Pin | Module Net
Connection Name: Wire (+15V)
W1 | DGND/15V_ISO3EXT_- | CB-P1-1 | DGND | DC-P9-1 | 15V_ISO3EXT_-
W2 | +15V/15V_ISO3EXT_+ | CB-P1-2 | +15V | DC-P9-2 | 15V_ISO3EXT_+
Connection Name: Wire (DC_IN_FB)
W1 | Vin_sns | CB-P17-1 | Vin_sns | DC-P8-1 | Vin_sns
W2 | Iin-_sns | CB-P17-2 | Iin-_sns | DC-P8-2 | Iin-_sns
W3 | Iin+_sns | CB-P17-3 | Iin+_sns | DC-P8-3 | Iin+_sns
W4 | IL1-_sns/Il1-_sns | CB-P17-4 | IL1-_sns | DC-P8-4 | Il1-_sns
W5 | IL1+_sns/Il1+_sns | CB-P17-5 | IL1+_sns | DC-P8-5 | Il1+_sns
Connection Name: Wire (DC_AC_FB)
W1 | IBRDG+_sns/NetP32_1 | CB-P18-1 | IBRDG+_sns | DC-AC-P32-1 | NetP32_1
W2 | IBRDG-_sns/NetP32_2 | CB-P18-2 | IBRDG-_sns | DC-AC-P32-2 | NetP32_2
W3 | VC1_2_sns/NetP32_3 | CB-P18-3 | VC1_2_sns | DC-AC-P32-3 | NetP32_3
W4 | VC1_sns/NetP32_4 | CB-P18-4 | VC1_sns | DC-AC-P32-4 | NetP32_4
W5 | AGND/SGND | CB-P18-5 | AGND | DC-AC-P32-5 | SGND
Connection Name: Wire (W_1)
W1 | VAC1_sns/NetP4_1 | CB-P19-1 | VAC1_sns | AC-P4-1 | NetP4_1
W2 | VAC2_sns/NetP4_2 | CB-P19-2 | VAC2_sns | AC-P4-2 | NetP4_2
W3 | AGND/SGND | CB-P19-3 | AGND | AC-P4-3 | SGND
W4 | A5V/5V | CB-P19-4 | A5V | AC-P4-4 | 5V
W5 | IAC_sns/NetIC1_12 | CB-P19-5 | IAC_sns | AC-P4-5 | NetIC1_12
W6 | O\C\_HV/NetC4_2 | CB-P19-6 | O\C\_HV | AC-P4-6 | NetC4_2
W7 | R\S\T\_HV/NetIC1_16 | CB-P19-7 | R\S\T\_HV | AC-P4-7 | NetIC1_16
Connection Name: Wire (W_10)
W1 | 5V/+5V_SW | CB-P20-1 | 5V | DRV-P18-1 | +5V_SW
W2 | R\S\T\_HV_3/RST_SW | CB-P20-2 | R\S\T\_HV_3 | DRV-P18-2 | RST_SW
W3 | F\L\T\_\F\D\_HV/FLT_SW | CB-P20-3 | F\L\T\_\F\D\_HV | DRV-P18-3 | FLT_SW
W4 | RDY_FD_HV/RDY_SW | CB-P20-4 | RDY_FD_HV | DRV-P18-4 | RDY_SW
W5 | DGND/GND_SW | CB-P20-6 | DGND | DRV-P18-6 | GND_SW
Connection Name: Wire (W_2)
W1 | IN_SW_HV_/IN_SW | CB-P28-4 | IN_SW_HV_ | DRV-P18-5 | IN_SW
Connection Name: Wire (W_3)
W1 | VSEL/NetP21_1 | DC-P1-1 | VSEL | CB-P21-1 | NetP21_1
W2 | PGND/DGND | DC-P1-3 | PGND | CB-P21-3 | DGND
W3 | +15V | DC-P1-4 | +15V | CB-P21-4 | +15V
Connection Name: Wire (W_4)
W1 | IN_SW_/IN_SW_FLT_HV_ | DC-P1-2 | IN_SW_ | CB-P28-3 | IN_SW_FLT_HV_
Connection Name: Wire (W_5)
W1 | +15V/+5V_SB1 | CB-P22-1 | +15V | DRV-P29-1 | +5V_SB1
W2 | DGND/GND_SB1 | CB-P22-3 | DGND | DRV-P29-3 | GND_SB1
Connection Name: Wire (W_6)
W1 | SB1_HV_/SB1 | CB-P29-3 | SB1_HV_ | DRV-P29-2 | SB1
Connection Name: Wire (W_7)
W1 | +15V/+5V_SB2 | CB-P24-1 | +15V | DRV-P30-1 | +5V_SB2
W2 | DGND/GND_SB2 | CB-P24-3 | DGND | DRV-P30-3 | GND_SB2
Connection Name: Wire (SW_ZR1)
W1 | RDY_HS1_HV_/RDY_HS_1 | CB-P26_2-5 | RDY_HS1_HV_ | DRV-P2-4 | RDY_HS_1
Connection Name: Wire (W_9)
W1 | 5V/+5V_ZR1 | CB-P26_2-1 | 5V | DRV-P23-1 | +5V_ZR1
W2 | R\S\T\_HV_7/RST_ZR1 | CB-P26_2-2 | R\S\T\_HV_7 | DRV-P23-2 | RST_ZR1
W3 | F\L\T\_\Z\R\1\_HV/FLT_ZR1 | CB-P26_2-3 | F\L\T\_\Z\R\1\_HV | DRV-P23-3 | FLT_ZR1
W4 | RDY_ZR1_HV/RDY_ZR1 | CB-P26_2-4 | RDY_ZR1_HV | DRV-P23-4 | RDY_ZR1
W5 | DGND/GND_ZR1 | CB-P26_2-6 | DGND | DRV-P23-6 | GND_ZR1
Connection Name: Wire (RDY_HS2)
W1 | RDY_HS2_HV_/RDY_HS_2 | CB-P20-5 | RDY_HS2_HV_ | DRV-P13-4 | RDY_HS_2
Connection Name: Wire (W_8)
W1 | 5V/+5V_ZR2 | CB-P25_2-1 | 5V | DRV-P20-1 | +5V_ZR2
W2 | R\S\T\_HV_6/RST_ZR2 | CB-P25_2-2 | R\S\T\_HV_6 | DRV-P20-2 | RST_ZR2
W3 | F\L\T\_\Z\R\2\_HV/FLT_ZR2 | CB-P25_2-3 | F\L\T\_\Z\R\2\_HV | DRV-P20-3 | FLT_ZR2
W4 | RDY_ZR2_HV/RDY_ZR2 | CB-P25_2-4 | RDY_ZR2_HV | DRV-P20-4 | RDY_ZR2
W5 | DGND/GND_ZR2 | CB-P25_2-6 | DGND | DRV-P20-6 | GND_ZR2
Connection Name: Wire (FLT_HS1)
W1 | FLT_HS1_HV_/FLT_HS_1 | CB-P25_2-5 | FLT_HS1_HV_ | DRV-P2-3 | FLT_HS_1

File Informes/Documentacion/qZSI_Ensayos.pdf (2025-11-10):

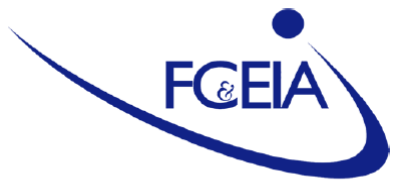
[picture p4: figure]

# PROCEDIMIENTO DE ENSAYOS

Año: 2025

Autores
Fasolato, Alejandro Claudio, F-3684/6 Soso, Alvaro Francisco, S-5571/9 Zuliani, Agustín Marcelo, Z-1183/5

Director
Vazquez Sieber, Andrés

Proyecto I - FCEIA - UNR | Procedimiento de ensayos

# Índice

## 1. Introducción

Para validar el funcionamiento del equipo será necesario realizar una serie de ensayos sobre el equipo. Primeramente se debe seguir el protocolo de conexionado y de puesta en marcha del equipo. Una vez encendido y funcionando en régimen, se realizará una serie de ensayos con el objetivo de verificar el correcto funcionamiento del convertidor a lazo abierto. Además, se efectuarán mediciones específicas para determinar la viabilidad de la implementación de controladores a lazo cerrado, dentro de ellos la caracterización de la respuesta a lazo abierto y validación del modelo.

Para validar la performance del control se realizarán ensayos de variación de carga y de tensión de fuente estudiando el rechazo a perturbaciones, como también el cambios de referencia. Se observará particularmente el tiempo y el sobrevalor de la respuesta.

La metodología adoptada será realizar una reunión donde se repasen y planifiquen las actividades a realizar previo a cada sesión de laboratorio, como también el análisis de las simulaciones correspondientes a reproducir en el laboratorio.

Se deberá contemplar el tiempo requerido para la realización de los mismos ya que entre cada uno se deberá resetear el convertidor para trabajar en condiciones seguras, y además tener en cuenta el tiempo de conexionado y guardado del SETUP. Detalles sobre la puesta en marcha se encuentran en el documento “Protocolo de puesta en marcha”.

Todos los ensayos se documentarán mediante registro fotográfico, capturas de osciloscopio y logs del Data Logger. Cada sesión contará con una hoja de resultados firmada, asegurando trazabilidad y reproducibilidad.

## 2. Consideraciones generales

Se deberá tener en consideración qué elementos, instrumentos y disposiciones de laboratorio se utilizarán a la hora de realizar los ensayos del convertidor. Como equipamiento básico se tendrá una fuente variable de alta tensión continua (que permita entregar hasta 500 V y 6 A en sus bornes respectivos), sumado a distintas resistencias variables que permitan realizar las variaciones de carga necesarias. Como instrumental, se contará con un osciloscopio de 4 canales, sondas de medición de corriente y sondas diferenciales de medición de tensión (sin contar los básicos multímetros y pinzas amperométricas de medición de valor eficaz). Cabe destacar que el detalle de funcionamiento, conexión y ajuste será profundizado en la documentación “uso y calibración del instrumental”.

Algunas consideraciones a tener en cuenta respecto de la respuesta ante variaciones a lazo abierto de carga, referencias, y fuente de alimentación son:
❖ | Incrementar la Carga (bajar la resistencia) implica una disminución de tensión de salida
| pero un aumento de corriente lo que resultaría en un aumento de corriente de entrada y
| en una caída de la tensión de bus
❖ | Incrementar Vo (aumentar M) incrementa la corriente de salida, por lo que la corriente
| de entrada también incremente pero la Vbus cae.
❖ | Incrementar la Vb (incrementar d0) implica un aumento en Vo y por lo tanto un
| incremento en la corriente de entrada y salida.
❖ | Incrementar la Vin, incrementa la Vbus lo que incrementa la Vo y por lo tanto la
| corriente de salida y de entrada consecuentemente.

Otras consideraciones generales respecto al funcionamiento del convertidor:
❖ | Pérdida de conexión entre la pc y el dsp por el ruido de un transitorio.
❖ | Uso de redes de snubber activas para todos los ensayos, verificando su correcto
| funcionamiento constantemente.

## 3. Ensayos a baja potencia

Primeramente se verificará el correcto funcionamiento del inversor en su conjunto, revisando que se genere correctamente la forma de onda a la salida y la secuencia de arranque sea correcta.

## 3.1. Objetivo

Comprobar que el convertidor funciona en condiciones seguras antes de llevarlo a su punto de trabajo nominal.

## 3.2. Mediciones

❖ Tensión del bus DC: alimentación con fuente limitada en corriente, esperar que VBUS suba y se estabilice.
❖ Tensión de salida AC a baja carga: verificar forma de onda senoidal y simetría.
❖ Corriente de entrada: debe ser continua y sin picos anormales, con bajo contenido armónico.

## 3.3. Protecciones

Se ajustarán los valores de protecciones adecuándose a las limitaciones de cada ensayo. Esto cumple un doble objetivo, por un lado permitir una operación segura para el ensayo configurado y para las personas que manipulen el equipo, por el otro permite testear la efectividad de las mismas llegada la condición de activación.

## 3.4. Verificaciones

Adicionalmente se observarán algunas mediciones del apartado 4.5, como las tensiones de gate de los transistores (4.5.B) para verificar las señales de conmutación sean generadas correctamente, las tensiones de snubber (4.5.C) para validar su funcionamiento y evitar fallas a futuro, y la tensión en bornes del diodo-transistor de la red qZ (4.5.E) para observar su comportamiento en conducción continua y discontinua.

## 3.5. Parámetros del ensayo

Para todos los ensayos la potencia será de 10W siendo un bajo porcentaje de la potencia en operación nominal. Los conjuntos de parámetros a configurar en cada repetición son:

Ensayo | Vin | VBUS | Vo | RL | do | M
1 | 50 | 80 | 50 | 120 | 0.1875 | 0.625
2 | 80 | 100 | 80 | 330 | 0.1 | 0.8
3 | 100 | 150 | 100 | 500 | 0.1666 | 0.6666
4 | 150 | 200 | 150 | 1100 | 0.125 | 0.75
5 | 200 | 300 | 200 | 2000 | 0.1666 | 0.6666

Siendo Vin la tensión de entrada, VBUS la tensión del bus de continua, Vo la tensión
pico de salida y RL la resistencia de carga conectada a la salida.
- Las resistencias de carga para lograr trabajo a baja potencia se encuentran en el laboratorio y no son las mismas que las de disipación de alta potencia.
- Deberá utilizarse un enchufe para poder conectarse al toma de alta tensión AC, y conectar la carga en los extremos del mismo.

## 3.6. Ejemplo práctico

Los conjuntos de valores a utilizar en cada repetición son:

Vin = 50V, VBUS = 80V, Vo = 50V, RL = 120Ω

Se requeriría, para elevar la tensión de Bus al valor deseado:

Vbus = Vi/(1 − 2 * d
0

)

80 V = 50 V/ (1 − 2 * d
0

)

80 V(1 − 2 * d
0

) = 50 V

160 . d

0 = 30 V

d

0 = 3/16 = 0. 1875

Dejando un espacio para desarrollar la tensión de salida tal que:

M < 1 − d

0 = 1 − 0. 1875 = 0. 8125

V

0 máx ≃ V
BUS

* 0. 8125 = 80 V * 0. 8125 = 65 V

## 3.7. Cálculo del modo de conducción

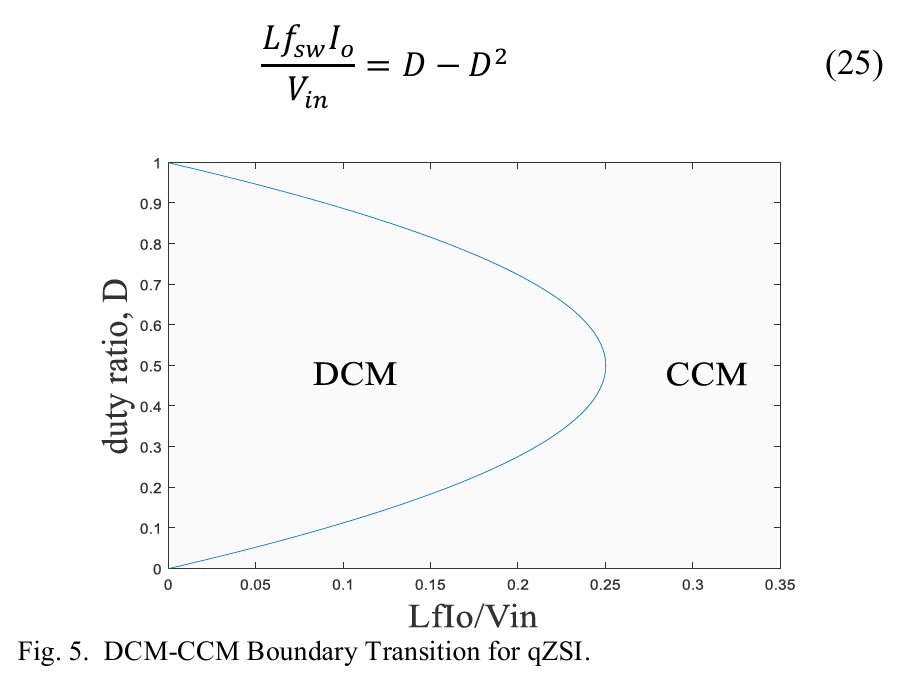
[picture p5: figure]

Donde L=L1=L2, y D=d0.

Notar que a medida que aumenta la tensión de entrada o disminuye la corriente de carga, es más factible ingresar en DCM según la VB requerida quien impondrá d0.

## 4. Ensayos de mediciones a LA

Una segunda serie de ensayos consiste en validar que todas las mediciones necesarias para la aplicación de los controladores sean correctas. Esto es, verificar que los valores registrados por el ADC, que llegan a los pines de la control card luego del acondicionamiento analógico y los que llegan crudos a los pines de la control board, se condigan con los medidos realmente sobre los circuitos, según sea el caso. Además se prestará particular atención al contenido de ruido sobre las mismas.

## 4.1. Objetivo

Comprobar que lo medido por el DSP a través del circuito analógico de acondicionamiento coincida con los valores reales. Esto asegura que los lazos de control puedan trabajar con información correcta.

## 4.2. Metodología

❖ Aplicar señales de referencia conocidas (ej. resistencia patrón, tensión de laboratorio). Este paso es crucial realizarlo en parada si no estuviera validado el funcionamiento.
❖ Medir con osciloscopio las señales que ingresan a la Control Board (antes del circuito analógico). Para posteriores ensayos, solamente se medirá en los test Points de la Placa de control.
❖ | Medir con el osciloscopio en los Test Point antes de la ControlCard.
❖ | Comparar contra la medición registrada por el ADC.
❖ | Calcular Error relativo.

## 4.3. Resultados esperados

❖ | Error < 5% entre medición real y digitalizada.
❖ | Confirmación de la linealidad en la transferencia del circuito acondicionador.

## 4.4. Parámetros del ensayo

Ensayo | Vin | VBUS | Vo | RL | do | M
1 | 50 | 80 | 50 | 120 | 0.1875 | 0.625
2 | 80 | 100 | 80 | 330 | 0.1 | 0.8
3 | 90 | 120 | 90 | 90 | 0.125 | 0.750
4 | 120 | 170 | 120 | 90 | 0.147 | 0.706
5 | 210 | 260 | 210 | 62 | 0.096 | 0.808
6 | 240 | 300 | 240 | 62 | 0.100 | 0.800

## 4.5. Mediciones

Todas las mediciones que puedan ser efectuadas sobre las fichas DB9 - DB15, se facilitarán al soldar pequeños conductores sobres los pines correspondientes.

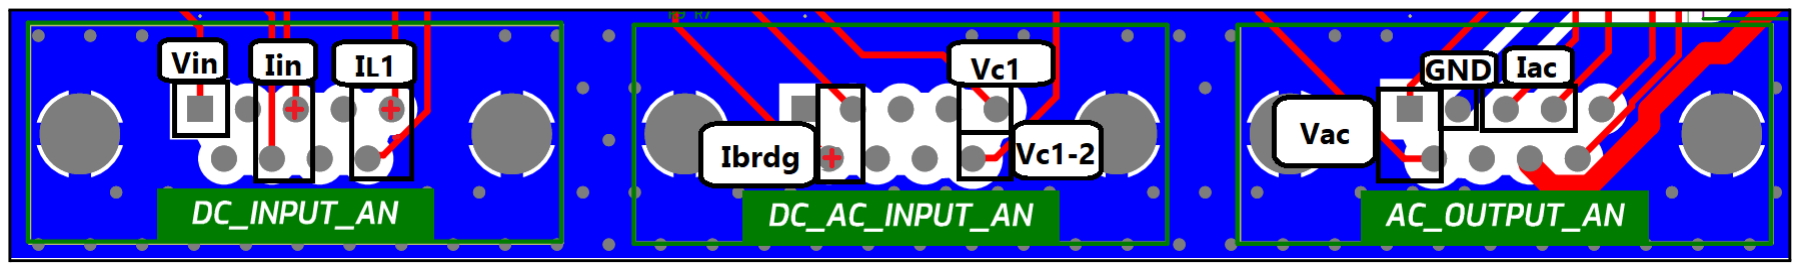
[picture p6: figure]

Mediciones. GND como referencia para mediciones simples, polaridad marcada con símbolo + sobre los pines de referencia.

Todas las tensiones que ingresen a la ControlCard se medirán con osciloscopio sobre los TP ubicados en la placa de control.

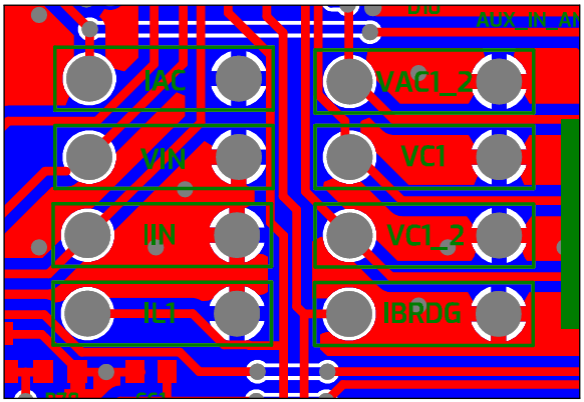
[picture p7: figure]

Test Points de mediciones que ingresan a la Control Card.

A. Tensión de BUS CC

❖ Dónde: Cables celeste y blanco, provenientes de los puertos P2 y P6. Se toma la masa del puente como la misma que la de la placa de control.

❖ Características de la medición
La tensión de BUS conmuta entre VB y 0, es una onda cuadrada y se encuentra en 0 durante los períodos de shoot-through. Se deberá verificar que se alcancen los valores 0 (en shoot-through) y VB (en período activo). Además se observará un rizado de 100Hz sobre la misma.

❖ Transferencia: Además de medir la tensión que llega a la ctrl card, se deberá medir con osc sobre los test points en la control card.

❖ Análisis de eventualidades y Plan contingencia
¿Por qué motivos los valores y forma de onda de Vbus no son los esperados?
Error en la carga del parámetro d0, o en su cálculo.
Incorrecta configuración de carga, tensión de entrada o tensión de salida en valores distintos a los propuestos por dicho ensayo.
La señal de shoot through no se efectúa debidamente, porque el PWM está mal configurado, ó porque los level shifters no responden correctamente, ó porque hay ruido en las señales que ingresan a los drivers, ó porque los drivers no se comportan debidamente.
Porque los capacitores no se encuentran en condiciones.
Se está trabajando en conducción discontinua debido a la baja carga.

B. Tensión de gate Transistores de baja del puente

❖ Dónde: Se miden los gate de los transistores del puente, para observar las conmutaciones. Se realiza la medición sobre los gate de los transistores de baja puesto que se encuentran referenciados a masa, no así los de alta (flotantes) Esto para medir en S_L_1 y en S_L_2 referenciando la masa para el osciloscopio.

No se podrán realizar estas mediciones sobre dicha placa a alta tensión debido a la peligrosidad del hecho. Las mismas se realizan en la Placa de Control, sobre la salida de los level shifters.

Se rastrearon las señales desde la placa de control hasta el conector D9 de Drivers, para determinar cuáles señales se medirán para ver las conmutaciones de los IGBT’s. Se deberá verificar el sincronismo entre los canales.

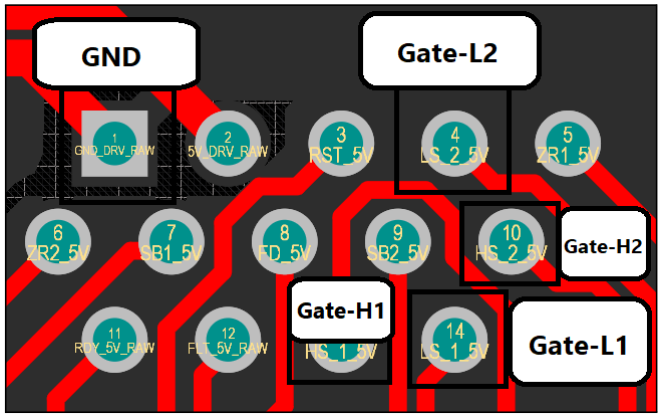
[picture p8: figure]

Mediciones. Referenciadas a GND, las 4 llaves respectivamente.

❖ Características de la medición
Se espera que la forma de onda sea una cuadrada de 0-5V SPWM variando su ancho de pulso. Además, comparando los canales A y B se podrá observar el desfase y sincronismo entre los mismos.

❖ Análisis de eventualidades y Plan contingencia
Incorrecta configuración del SPWM, valores de comparación, clock, sincronismo Ruido sobre la medición.
Alguna falla en los level-shifters, de alimentación por ejemplo.

C. Diodo-Transistor qZS

❖ Dónde Para medir la conmutación del diodo Vd, se requerirá medir entre P1 y P3. Para acceder a la medición se deberá recurrir a cables auxiliares para la medición. También se observará la conmutación del gate del transistor sobre el DB15.

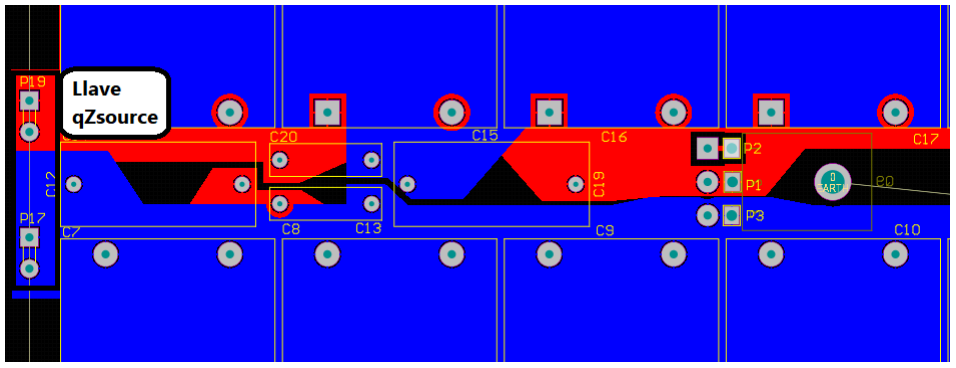
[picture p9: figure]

❖ Características de la medición
Se puede observar la señal del gate del transistor / diodo qz cuando baja la carga (baja la corriente de salida por aumento de la Rl o disminución de Vo), se puede entrar en modo conducción discontinua y allí debe verse la utilidad del transistor en permitir el paso de corriente en sentido contrario. Particularmente encendiéndose en los intervalos de NO-shoot-through, puesto que durante el shoot-through se produciría un corto entre los Capacitores de la red qZS.

Por otro lado, recordar que el diodo se pondrá en conducción (Vdiodo = 0) durante los intervalos NO-Shoot-through, y no conducirá en los intervalos shoot-through, resistiendo un valor en inversa equivalente a C1-C2.

❖ Análisis de eventualidades y Plan contingencia
Que la tensión sobre el diodo no sea la mencionada es crítico ya que provocaría un valor de VBUS erróneo y posiblemente un cortocircuito.
Porque existe una falla en los capacitores
Porque existe una incorrecta activación del transistor correspondiente. Porque el shoot-through está funcionando incorrectamente.

D. Tensión de salida Vac

❖ Dónde Puntas diferenciales sobre la entrada de la señal a la placa de control, medición diferencial.

❖ Características de la medición
La señal de salida es una senoidal con valor de pico según el índice de modulación, deberá verificarse su simetría y pureza armónica.

❖ Transferencia: Además de medir la tensión que llega a la ctrl card, se deberá medir con osc sobre los test points en la control card.

❖ Análisis de eventualidades y Plan contingencia
Si la tensión de salida no cumple con su valor esperado puede deberse a:
Una configuración errónea del índice de modulación.
Una carga o tensión de bus no correspondiente al ensayo.
Un incorrecto funcionamiento de la PWM y por lo tanto no producción del vector activo
Si no cumple con la forma deseada:
Puede deberse a un malfuncionamiento de los drivers o level shifters,
Si no cumple con el contenido armónico:
Falla en el filtro de salida
Ruido en la medición

E. Tensión de snubber

❖ Dónde
❖ Características de la medición
❖ Análisis de eventualidades y Plan contingencia

F. Corriente de salida Iac

❖ Dónde se mide sobre los cables de salida con pinza amp, y osc en en el arribo de la señal que referencia la tensión entregada por el sensor de efecto hall.

❖ Características de la medición
Se espera que la corriente posea una forma de onda senoidal, por se la carga puramente resistiva apenas desfasada de la tensión debido al filtro de salida.

❖ Transferencia: Además de medir la tensión que llega a la ctrl card, se deberá medir con osc sobre los test points en la control card.
- Transferencia del sensor hall

Con V OFFSET = 2. 5V

❖ Análisis de eventualidades y Plan contingencia Puede deberse a una incorrecta configuración de la carga. Falla en el sensor de efecto hall.
Ruido en la medición.

G. Corriente por el inductor L1

❖ Dónde sobre un shunt para medir tensión sobre el mismo que llega a la placa de control, FLOTANTE, se puede poner el cocodrilo a masa y usar la diferencia de los dos canales. Medir la tensión que llega a la ctrl card.

❖ Características de la medición
Se espera que la corriente por el inductor L1 se comporte como una triangular, en la que durante los intervalos de shoot-through la misma se recarga por los capacitores, y durante los intervalos de NST devuelve la energía hacia los capacitores recargándolos.

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

❖ Análisis de eventualidades y Plan contingencia
Incorrecta activación del vector shoot-through Falla en el diodo de la red Z
Conducción discontinua

H. Corriente por el puente

❖ Dónde Se mide en la entrada al puente H y es IL1 + IL2 diferencial.
- La I bridge será la de salida, pero muestreada en la mitad del vector activo. Alternativa para medir la corriente de salida i0, que no es la misma que circula la carga!!!! Esa sería i_load
- IL1 + IL2 muestreadas en la mitad del vector shoot-through.

❖ Características de la medición
FALTA

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

❖ Análisis de eventualidades y Plan contingencia
El muestreo no se está realizando adecuadamente en los intervalos.

I. Corriente de entrada I_in
Si se debiera implementar algún MPPT será necesario verificar en detalle esta variable.

❖ Dónde Existe una R shunt que refleja el valor en tensión, la medición se efectuará sobre la placa de control

❖ Características de la medición
Se espera que la corriente de entrada sea lo más continua posible, debido al filtro de entrada y al inductor L1 de la red Z. Sin embargo como la misma se encuentra entre tensiones 0 y Vin por conmutación, aparecerá un ripple por la carga-descarga de L1.

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

❖ Análisis de eventualidades y Plan contingencia
Puede deberse a fallas en el filtro de entrada.
Fallas en los inductores de la red.
Configuración incorrecta de los parámetros del ensayo.

## 5. Ensayos de Verificación de funcionamiento

El grupo de ensayos descrito a continuación apunta a verificar el funcionamiento del equipo según lo informado en el proyecto base. Además de revalidar los resultados, se aprovechará la instancia para practicar, permitiendo así un mejor manejo del equipo a futuro.

## 5.1. Objetivo

El objetivo de esta serie de ensayos es confirmar que el equipo se comporta según los resultados de los ensayos del proyecto base.

## 5.2. Metodología

❖ | Barrido de tensión del bus con distintas consignas de duty d0.
❖ | Barrido de tensión de salida con distintas consignas de duty D.
❖ | Medición de rizado de corriente de entrada a diferentes cargas.
❖ | Verificación de forma de onda de salida a diferentes cargas.

## 5.3. Comparación

❖ | Graficar resultados actuales vs resultados previos.
❖ | Documentar diferencias (ej. por cambios en componentes, montaje o
condiciones de laboratorio).
❖ Re-calcular la eficiencia.

RESULTADOS ESPERADOS: coherencia con curvas y tablas del informe anterior.

## 5.4. Valores típicos y características

❖ | Cargas resistivas de valores entre 90 y 60.
❖ | Tensiones de entrada entre 50 y 300V.
❖ | No es deseable que la corriente de entrada In no sea ctte. Para ello el filtro entre
| la fuente y la entrada.
❖ | No es deseable que Vin no sea constante durante los períodos activos, pero como
| el equipo funcionará a LA oscilará entre ciclo y ciclo de switching.

## 5.5. Parámetros para los ensayos

Ensayo | Vin | VBUS | Vo | RL | do | M
1 | 90 | 120 | 90 | 90 | 0.125 | 0.750
2 | 120 | 170 | 120 | 90 | 0.147 | 0.706
3 | 150 | 200 | 150 | 90 | 0.125 | 0.750
4 | 180 | 230 | 180 | 90 | 0.109 | 0.783
5 | 210 | 260 | 210 | 90 | 0.096 | 0.808
6 | 240 | 300 | 240 | 90 | 0.100 | 0.800
7 | 270 | 350 | 270 | 90 | 0.114 | 0.771
8 | 290 | 385 | 290 | 90 | 0.123 | 0.753
9 | 300 | 400 | 300 | 90 | 0.125 | 0.750
10 | 150 | 200 | 150 | 62 | 0.125 | 0.750
11 | 210 | 260 | 210 | 62 | 0.096 | 0.808
12 | 240 | 300 | 240 | 62 | 0.100 | 0.800
13 | 270 | 350 | 270 | 62 | 0.114 | 0.771
14 | 300 | 400 | 300 | 62 | 0.125 | 0.763

## 6. Ensayos de caracterización y validación del modelo LA

Es de interés particular observar el tiempo de respuesta, sobrevalor, característica transitoria, y respuesta en frecuencia a lazo abierto para validar el modelo y los parámetros utilizados en las simulaciones.

## 6.1. Objetivo

El objetivo de esta etapa es caracterizar el comportamiento dinámico y estacionario del inversor quasi-Z-source en lazo abierto, con el fin de validar el modelo promediado y obtener parámetros experimentales equivalentes a los utilizados en simulación y diseño de control.

Se busca verificar la coherencia entre las variables teóricas, simuladas y medidas, identificando la frecuencia natural del sistema, el amortiguamiento y la respuesta ante perturbaciones de entrada, carga y consigna.

## 6.2. Metodología

Se aplicarán variaciones de carga, setpoint y fuente para cada ensayo sobre puntos de trabajo de baja potencia para evitar exigir el convertidor a lazo abierto. Como condición se deberá asegurar que las corrientes en inductores nunca caen a cero (sino, el modelo promediado pierde validez).

❖ | Regulación de Setpoint: variación de Vbus al variar SP.
❖ | Line regulation: variación de Vbus al variar Vin.
❖ | Load regulation: variación de Vbus frente a cambios en resistencia de carga. Se
| producirán con un relé y un generador de señal, añadiendo o quitando cargas
| resistivas en paralelo.

## 6.3. Resultados esperados

Principalmente se busca obtener los valores reales del amortiguamiento y la frecuencia natural del sistema. Además se validará la transferencia entre las variaciones y la salida.

## 6.4. Ensayo 1 – Respuesta a variaciones de d0

6.4.1. Objetivo

verificar la relación entre la tensión del bus Vbus y el ciclo de shoot-through d0.

6.4.2. Procedimiento
1. Aplicar escalón de d0
2. Registrar Vbus, Vout e Iin para cada punto, manteniendo carga y tensión de entrada constante.
3. Calcular la ganancia experimental: G=Vbus/Vin
y comparar con la expresión teórica: Gteo=1/1 - 2d_0
4. Identificar posibles desviaciones y justificar por pérdidas, ESR o caídas en diodos/MOSFETs.
6.4.3. Parámetros del ensayo
Ensayo | Vin | VBUS | Vo | RL | do | M
1 | 90 | 120 + 12 | 90 | 90 | 0.125 | 0.750
2 | 210 | 260 + 26 | 210 | 90 | 0.096 | 0.808
Ensayo | Vin | VBUS | Vo | RL | do | M
3 | 90 | 120 | 90 + 9 | 90 | 0.125 | 0.750
4 | 210 | 260 | 210 + 21 | 90 | 0.096 | 0.808
6.4.4. Resultado esperado
❖ | Incrementar Vo (aumentar M) incrementa la corriente de salida, por lo que la corriente
| de entrada también incremente pero la Vbus cae.
❖ | Incrementar la Vb (incrementar d0) implica un aumento en Vo y por lo tanto un
| incremento en la corriente de entrada y salida.

## 6.5. Ensayo 2 – Respuesta temporal del bus ante variación de carga

6.5.1. Objetivo

Determinar la frecuencia natural ωn y el factor de amortiguamiento ξ del sistema.

6.5.2. Procedimiento
1. Operar el inversor con un d0.
2. Conmutar escalonadamente una segunda carga resistiva mediante relé.
3. Registrar Vbus e Iin durante el transitorio.
4. Medir sobrepico y tiempo de establecimiento ts.
5. Calcular , donde tr2% es el tiempo respuesta al 2% y Sv el sobrevalor relativo.

wn =

4
ξ . t
r2%

y ξ =

log(Sv)

π

2+log(Sv)

2

6.5.3. Parámetros del ensayo
Ensayo | Vin | VBUS | Vo | RL | do | M
5 | 90 | 120 | 90 | 90 - 30 | 0.125 | 0.750
6 | 210 | 260 | 210 | 90 - 30 | 0.096 | 0.808
6.5.4. Resultado esperado

❖ Incrementar la Carga (bajar la resistencia) implica una disminución de tensión de salida pero un aumento de corriente lo que resultaría en un aumento de corriente de entrada y en una caída de la tensión de bus

## 6.6. Ensayo 3 – Respuesta a variaciones de tensión de entrada

6.6.1. Objetivo

Evaluar la capacidad del qZ-network para mantener la proporción de ganancia G ante fluctuaciones de entrada.

6.6.2. Procedimiento
1. Fijar carga y d0.
2. Aplicar un escalón de Vin.
3. Registrar Vbus y corriente de entrada.
4. Comparar la variación de G=Vbus/Vin respecto a la simulación.
6.6.3. Parámetros del ensayo
Ensayo | Vin | VBUS | Vo | RL | do | M
7 | 90 + 9 | 120 + | 90 | 90 | 0.125 | 0.750
8 | 210 + 21 | 260 + | 210 | 90 | 0.096 | 0.808
6.6.4. Resultado esperado

❖ Incrementar la Vin, incrementa la Vbus lo que incrementa la Vo y por lo tanto la corriente de salida y de entrada consecuentemente.

## 7. Ensayos de performance LC

La última instancia de ensayos consiste en la verificación de la implementación de los controladores de tensión de bus y de salida. Adicionalmente, se propone someter al convertidor ante perturbaciones de carga y fuente, como variaciones de consigna para poder estudiar su performance en términos de tiempo de respuesta, sobrevalor y error en estado estacionario.

## 7.1. Objetivo

El objetivo de esta serie de ensayos es comprobar el desempeño de los controladores de tensión de bus y salida. Se replican las simulaciones realizadas para esta instancia.

No solo se deberá comprobar el tiempo de respuesta y sobrevalor ante perturbaciones y cambios de SP diseñados, sino también calcular la eficiencia a lazo cerrado y estudiar la forma de onda de salida.

## 7.2. Metodología

Al implementar por primera vez el controlador de Vbus o Vout se deberá realizar la prueba segura y verificar estabilidad.

La etapa consiste en dos series de ensayos, primero se evalúa al control de tensión de bus, y luego al de salida. Se aplicarán 3 juegos de ensayos de variación sobre 3 puntos de trabajo en potencia, a baja, media y alta potencia.

Por último, una vez validada la estabilidad, funcionamiento y performance, se realizará un ensayo en el que se exija al convertidor hasta su límite para poder así documentarlo.

Variaciones sobre los puntos de trabajo:

❖ Aplicar escalones de carga y medir sobrepico, tiempo de establecimiento y error en régimen permanente. Verificar la regulación.
❖ Aplicar cambios de Vin y verificar rechazo.
❖ Aplicar cambios de consigna y verificar seguimiento.

## 7.3. Re-cálculo de eficiencia

Con los resultados obtenidos se recalcula la eficiencia del convertidor, comparando con la obtenida a lazo abierto, esperando que el nuevo valor sea igual o levemente menor.

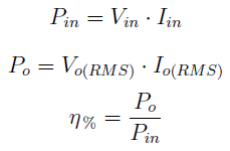
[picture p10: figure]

## 7.4. Ajuste de parámetros en lazos

De ser necesario, se deberán ajustar los parámetros de los lazos para mejorar la performance de los mismos. Llegado el caso, se deberá documentar el cambio y su justificación adecuadamente, como también re-simular con los ajustes realizados.

## 7.5. Resultados esperados

Finalizada la serie de ensayos descrita en la sección 7, se apunta a obtener los siguientes valores de funcionamiento:

❖ Error estático < 5 % en ambos lazos.
❖ Tiempo de establecimiento < 5 ms para el bus, < 20 ms para la salida. ❖ Sobrevalor < 10 %.
❖ THD dentro de los límites normativos (< 5 %).
❖ Eficiencia > 80%.

Por último, se logrará caracterizar al inversor en su rango operativo y limitaciones según:

❖ Potencia maxima.
❖ Tensión de entrada mínima y máxima Vin.
❖ Tensión mínima y máxima de salida Vout.

## 7.6. Parámetros del ensayo variación para V bus

Ensayo de estabilidad

Ensayo | Vin | VBUS | Vo | RL | do | M
1 | 30 | 50 | 30 | 180

Ensayos de variación para V bus

Ensayo | Vin | VBUS | Vo | RL | do | M
1 | 50 | 80 | 50 | 120 | 0.1875 | 0.625
1A | -5 | REG | 50 | 120
1B | 50 | +8 | 50 | 120
1C | 50 | REG | 50 | -12
Ensayo | Vin | VBUS | Vo | RL | do | M
2 | 120 | 170 | 120 | 90 | 0.147 | 0.706
2A | -12 | REG | 120 | 90
2B | 120 | +17 | 120 | 90
2C | 120 | REG | 120 | -9
Ensayo | Vin | VBUS | Vo | RL | do | M
3 | 240 | 300 | 240 | 62 | 0.100 | 0.800
3A | -24 | REG | 240 | 62
3B | 240 | +30 | 240 | 62
3C | 240 | REG | 240 | -6

## 7.7. Parámetros del ensayo variación para V out

Ensayo de estabilidad

Ensayo | Vin | VBUS | Vo | RL | do | M
1 | 30 | 50 | 30 | 180

Ensayos de variación para V out

Ensayo | Vin | VBUS | Vo | RL | do | M
1 | 50 | 80 | 50 | 120 | 0.1875 | 0.625
1A | -5 | REG | REG | 120
1B | 50 | REG | +5 | 120
1C | 50 | REG | REG | -12
Ensayo | Vin | VBUS | Vo | RL | do | M
2 | 120 | 170 | 120 | 90 | 0.147 | 0.706
2A | -12 | REG | REG | 90
2B | 120 | REG | +12 | 90
2C | 120 | REG | REG | -9
Ensayo | Vin | VBUS | Vo | RL | do | M
3 | 240 | 300 | 240 | 62 | 0.100 | 0.800
3A | -24 | REG | REG | 62
3B | 240 | REG | +24 | 62
3C | 240 | REG | REG | -6

## 7.8. Parámetros de ensayos exigentes

Consignas exigentes

Ensayo | Vin | VBUS | Vo | RL | do | M
1 | 120 | 300 | 195 | 62 | 0.3 | 0.650

Carga (potencia de salida) exigente

Ensayo | Vin | VBUS | Vo | RL | do | M
2 | 300 | 400 | 311 | 62

## 00 - Plantilla de ensayos a Baja Potencia - Fecha

Ensayo | Vin | VBUS | Vo | Iin

1

2

3

4

5

Observación:

Ensayo | Vo rms | Io rms | Pin | Pout | n

1

2

3

4

5

## 01 - Plantilla de mediciones - Ensayo X - Fecha

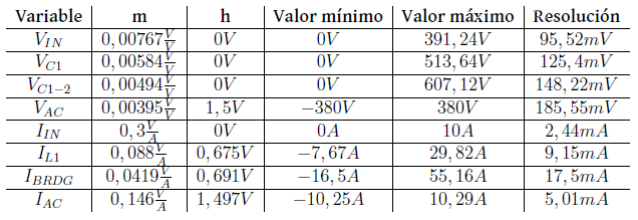
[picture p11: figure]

Medición | Valor real | CtrlCard | DSP | Error
| xx+- | Luego de la transfer nn | xx+- | Real-DSP/Real

V_BUS

V_ac

I_ac

i_L1

I_Bridge

i _in

Observación:

## 02 - Plantilla de validación funcionamiento - Fecha

Ensayo | Vin | VBUS | Vo | Iin

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
Observación:

## 02 - Plantilla de validación funcionamiento - Cálculos - Fecha

Observación:

Ensayo | Vo rms | Io rms | Pin | Pout | n

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
## 03 - Plantilla de caracterización a LA - Fecha

Ensayo | Vin | VBUS | Vo | RL | Iin | do | M

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
Observación:

## Plantilla de eficiencia para V bus

Observación:

Ensayo | Iin | Vo rms | Io rms | Pin | Pout | n

1

2

3

## Plantilla de eficiencia para V out

Observación:

Ensayo | Iin | Vo rms | Io rms | Pin | Pout | n

1

2

3

## Plantilla de eficiencia en ensayos exigentes

Observación:

Ensayo | Iin | Vo rms | Io rms | Pin | Pout | n

1

2

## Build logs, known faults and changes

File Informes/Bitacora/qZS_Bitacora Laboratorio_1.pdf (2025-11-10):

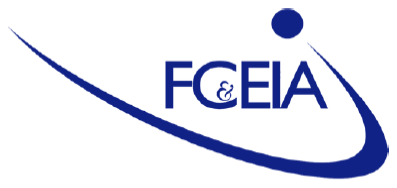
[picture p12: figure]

# PROCEDIMIENTO DE ENSAYOS

Año: 2025

Autores
Fasolato, Alejandro Claudio, F-3684/6 Soso, Alvaro Francisco, S-5571/9 Zuliani, Agustín Marcelo, Z-1183/5

Director
Vazquez Sieber, Andrés

Proyecto I - FCEIA - UNR | Procedimiento de ensayos

# 1.Introducción

Este documento consiste en una bitácora para llevar una trazabilidad del/los ensayo/s realizado/s durante la sesión de laboratorio de la fecha. De esta forma nos permitirá realizar un seguimiento más profundo de lo trabajado durante el laboratorio, para luego poner por escrito todo esto en un documento final que será parte del informe final. Las ventajas de realizar dicha documentación es que podremos ver el avance y luego realizar un manual de posibles problemas con el equipo. Con esta última idea el usuario que luego intente manejar el equipo podrá acudir a esta especie de manual para poder solucionar los inconvenientes que a nosotros mismos se nos presentó durante los ensayos realizados.

Fecha: 3/10/25 (Lunes)
Hora de inicio: 18hs
Hora de finalización: 21 hs Lugar: Laboratorio de Potencia

Integrantes presentes:

- Alejandro, Fasolato
- Álvaro, Soso

# 2.Objetivos del Ensayo

Describir brevemente el propósito del día de laboratorio.

Descripción: realizar un ensayo de Vin = 50, Vbus = 80 y Vo = 50

# 3.Configuración del sistema

- Modo de operación del ensayo: Lazo abierto
- Tensión de entrada (Vin): 50 V
- Carga conectada: Nose
- Frecuencia de conmutación: 10 KHz
- Control activo: LA
- Versión del firmware: v1.0
- Notas sobre el hardware (drivers, protecciones activas, pote. digitales configurados, etc.):

Notas extras:

# 4.Ensayos realizados

N° | Descripción del Ensayo | Condiciones | Resultados esperados

Resultados
obtenidos | Observaciones
1 | 50-80-50 | Lazo abierto Baja potencia

Vin = 50 V
VBus = 80 V
V0 = 50 V

Correctos

Se detecta que en
el mismo la
tensión de bus no
parecía subir
hasta 30v, resulta
que las los
escalados en el
osc estaban en x
10 en lugar de
x50, la tensión de
salida se
encontraba en 20V
de pico, lo que no
nos dimos cuenta
en ese momento
es que aún faltaba
el paso de
aumentar la Vo.

# 5.Resultados y mediciones

Adjuntar capturas de osciloscopio, registros de variables (Vdc, Iac, Vas, etc.) o comentarios relevantes sobre el comportamiento observado. Las imágenes pueden ir en otro documento ya definido para ensayos.

Descripción: La mediciones realizadas fueron Vbus, Vo, Vin, Iin (Nose bien la verdad no fui ese lunes).

# 6.Problemas presentados

La idea de esta sección es nombrar todos los problemas que se presentaron durante el ensayo del día de laboratorio. Estos problemas pueden incluir mal manejo del instrumental, fallos en el hardware (componentes en mal estado, conexiones sin buen contacto, protecciones activadas), errores de software y demás cosas que sean destacables. Junto con dicho problema deberá ponerse la solución encontrada y en caso de no lograrse solucionarlo en la misma sesión de laboratorio mencionarlo.

Descripción del problema: Se detecta que en el mismo la tensión de bus no parecía subir hasta 30v, resulta que las escalas en el osc estaban en x10 en lugar de x50, la tensión de salida se encontraba en 20V de pico, lo que nos dimos cuenta en ese momento es que aún faltaba el paso de aumentar la V0.

Resultó que al hacer zoom en Vbus, se veía un 1er orden, entonces dijimos es la punta, y resulta que la punta estaba mal conectada a las pinzas.

Solución:

Nota:

# 7. Ideas y tareas para próximos ensayos

En esta sección se incluirá una breve descripción del ensayo que se realizará la próxima sesión de laboratorio. En este deberá incluir todas las cosas necesarias para poder llevarla a cabo, a decir configuraciones de software, modificaciones de hardware, instrumental extra, etc.

Descripción breve del siguiente ensayo a realizar: -

Modificaciones necesarias para poder llevarlo a cabo (mod. de hardware, software, etc.): -

Elementos extra a utilizar: -

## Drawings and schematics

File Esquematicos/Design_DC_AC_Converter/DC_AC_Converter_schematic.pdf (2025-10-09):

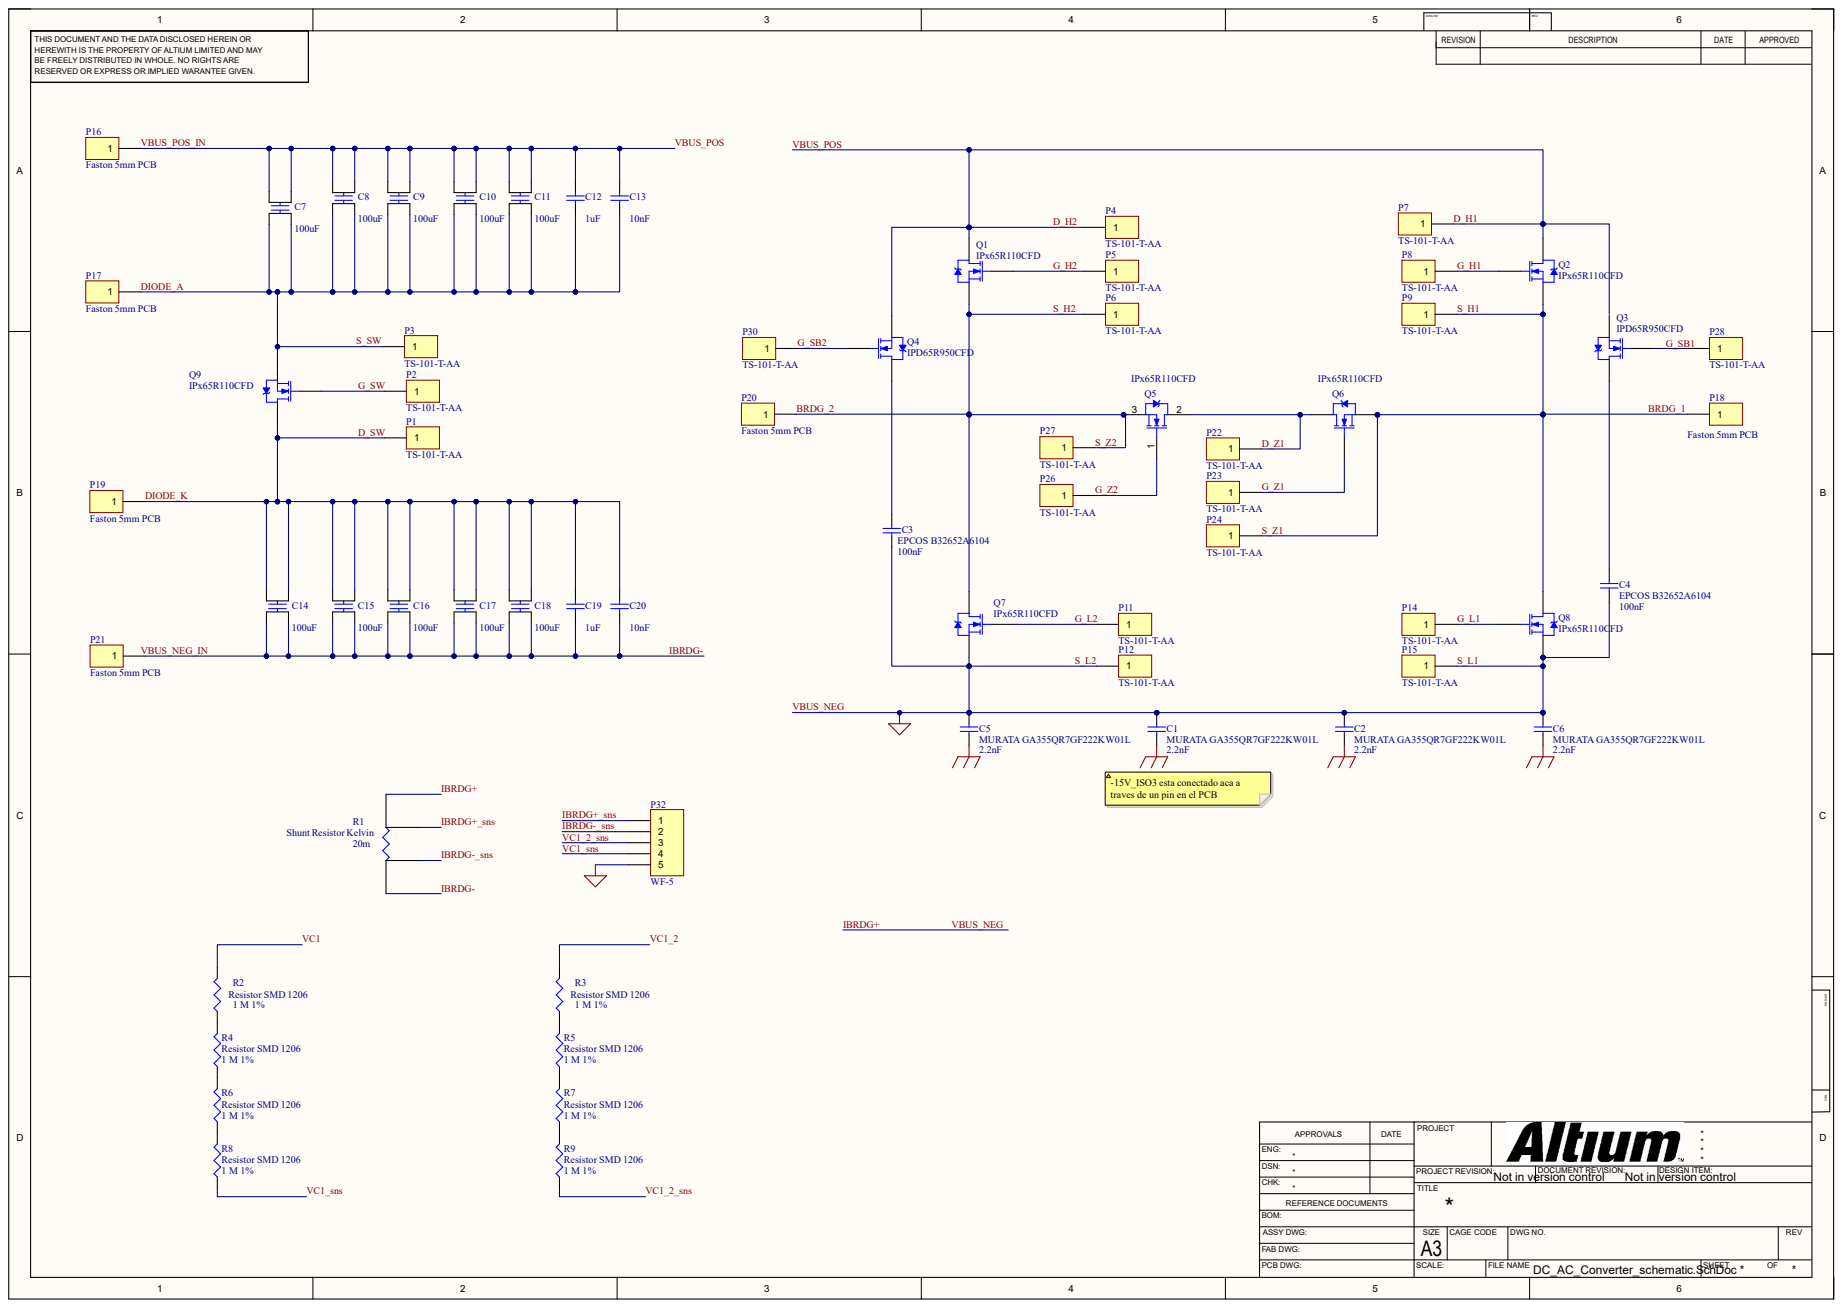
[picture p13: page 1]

1 | 2 | 3 | 4 | 5 | DWG NO: | REV: | 6

THIS DOCUMENT AND THE DATA DISCLOSED HEREIN OR HEREWITH IS THE PROPERTY OF ALTIUM LIMITED AND MAY BE FREELY DISTRIBUTED IN WHOLE. NO RIGHTS ARE RESERVED OR EXPRESS OR IMPLIED WARANTEE GIVEN. | | REVISION | DESCRIPTION | DATE | APPROVED

-15V_ISO3 esta conectado aca a
traves de un pin en el PCB

APPROVALS | DATE | PROJECT | * *

ENG: *
DSN: * | | PROJECT REVISION: | DOCUMENT REVISION: Not in version control | DESIGN ITEM: Not in version control
CHK: *

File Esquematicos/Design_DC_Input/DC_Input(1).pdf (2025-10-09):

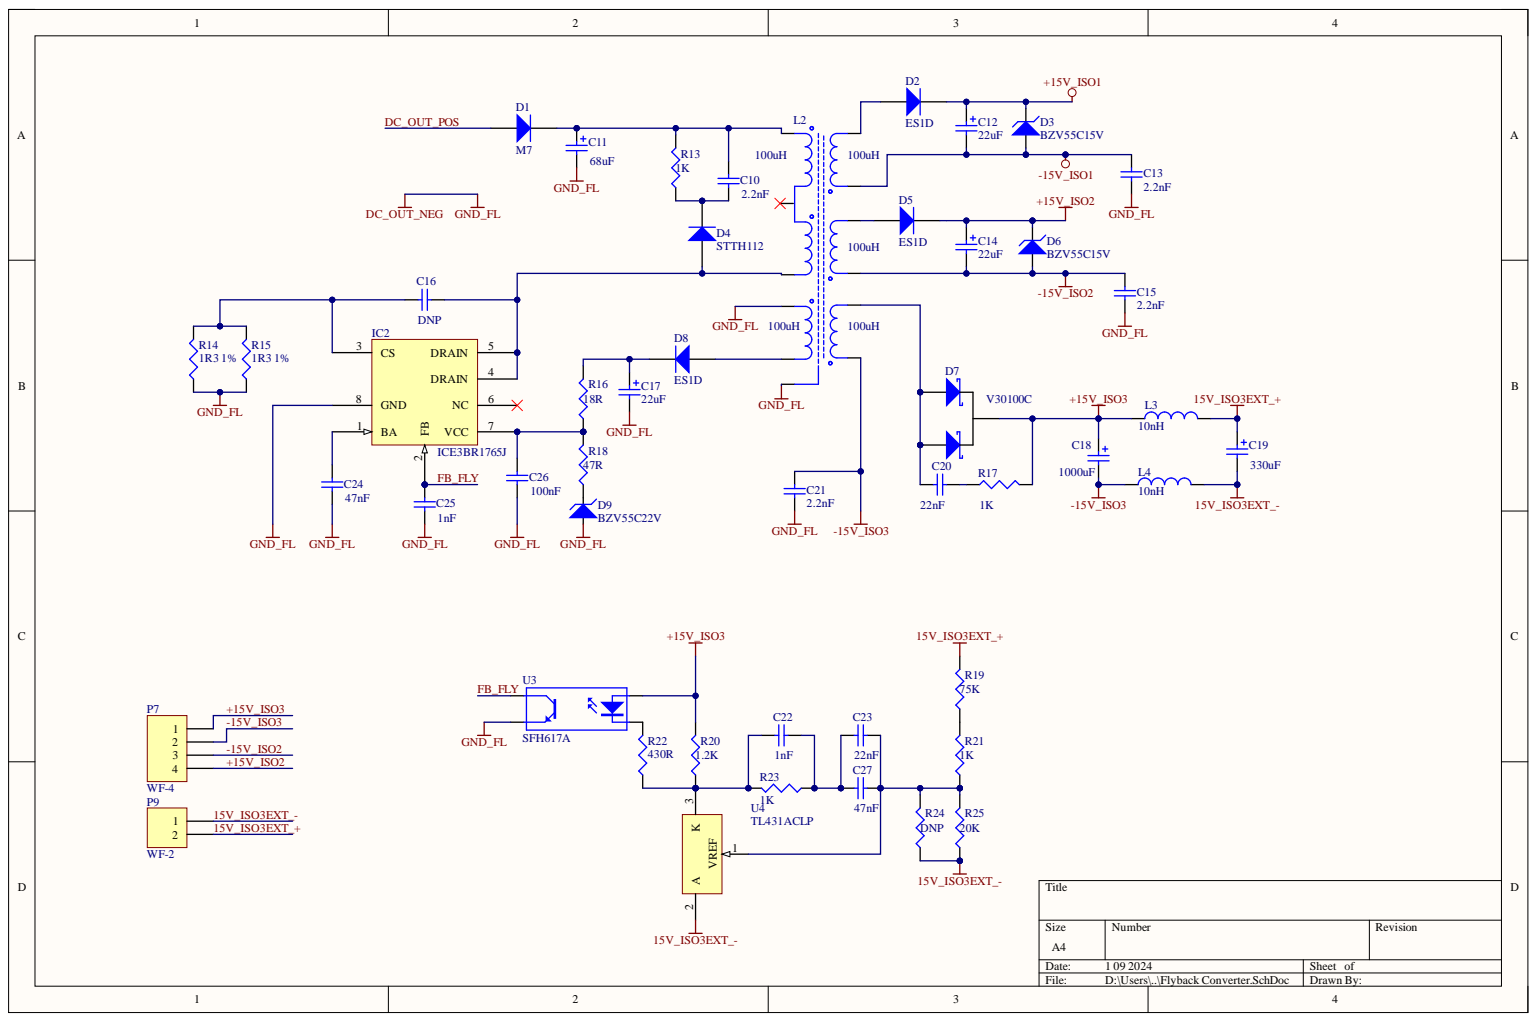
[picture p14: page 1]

R20 1.2K | TL431ACLP | 1K | 22nF

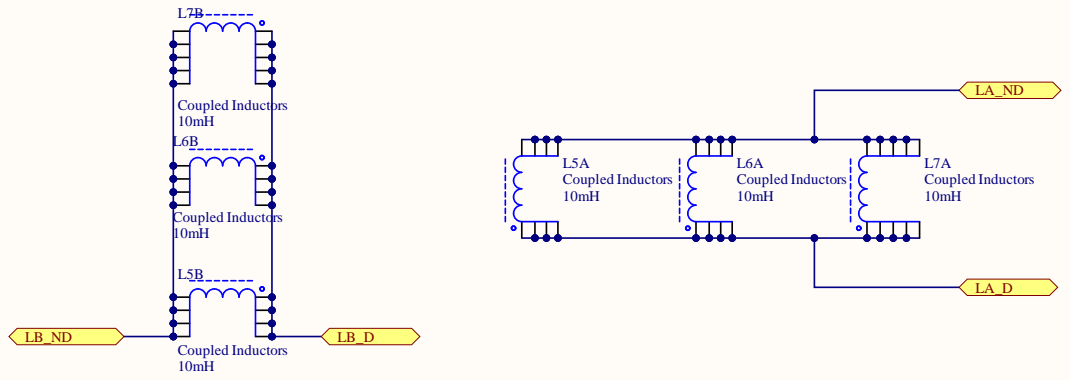
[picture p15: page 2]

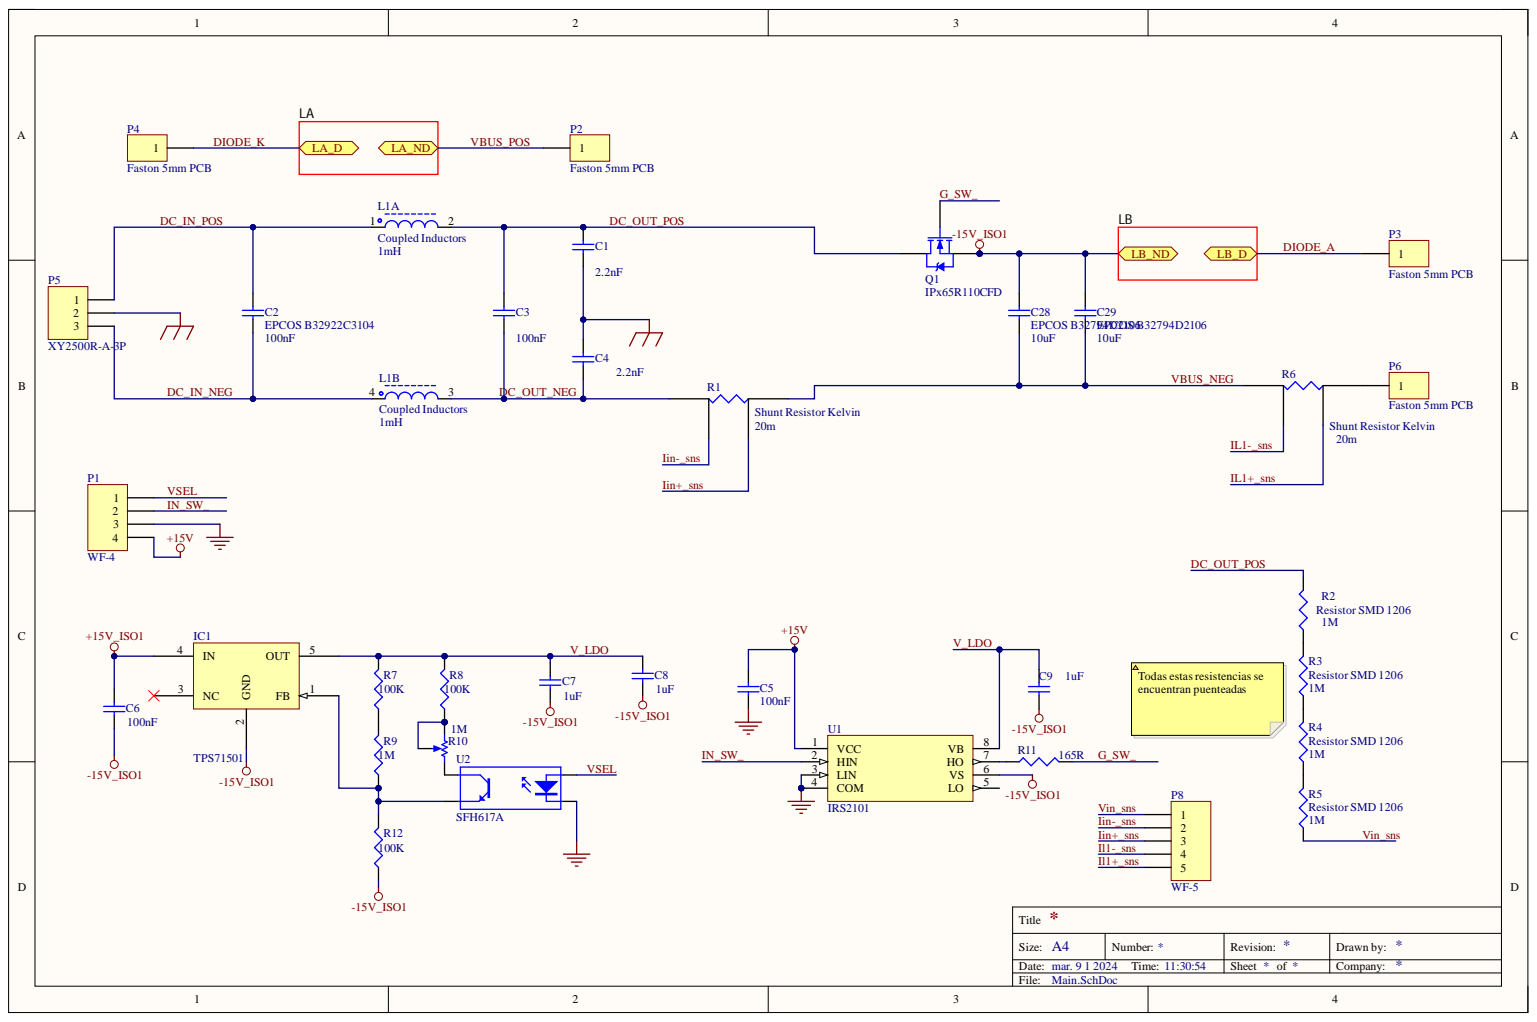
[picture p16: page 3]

Todas estas resistencias se
encuentran puenteadas

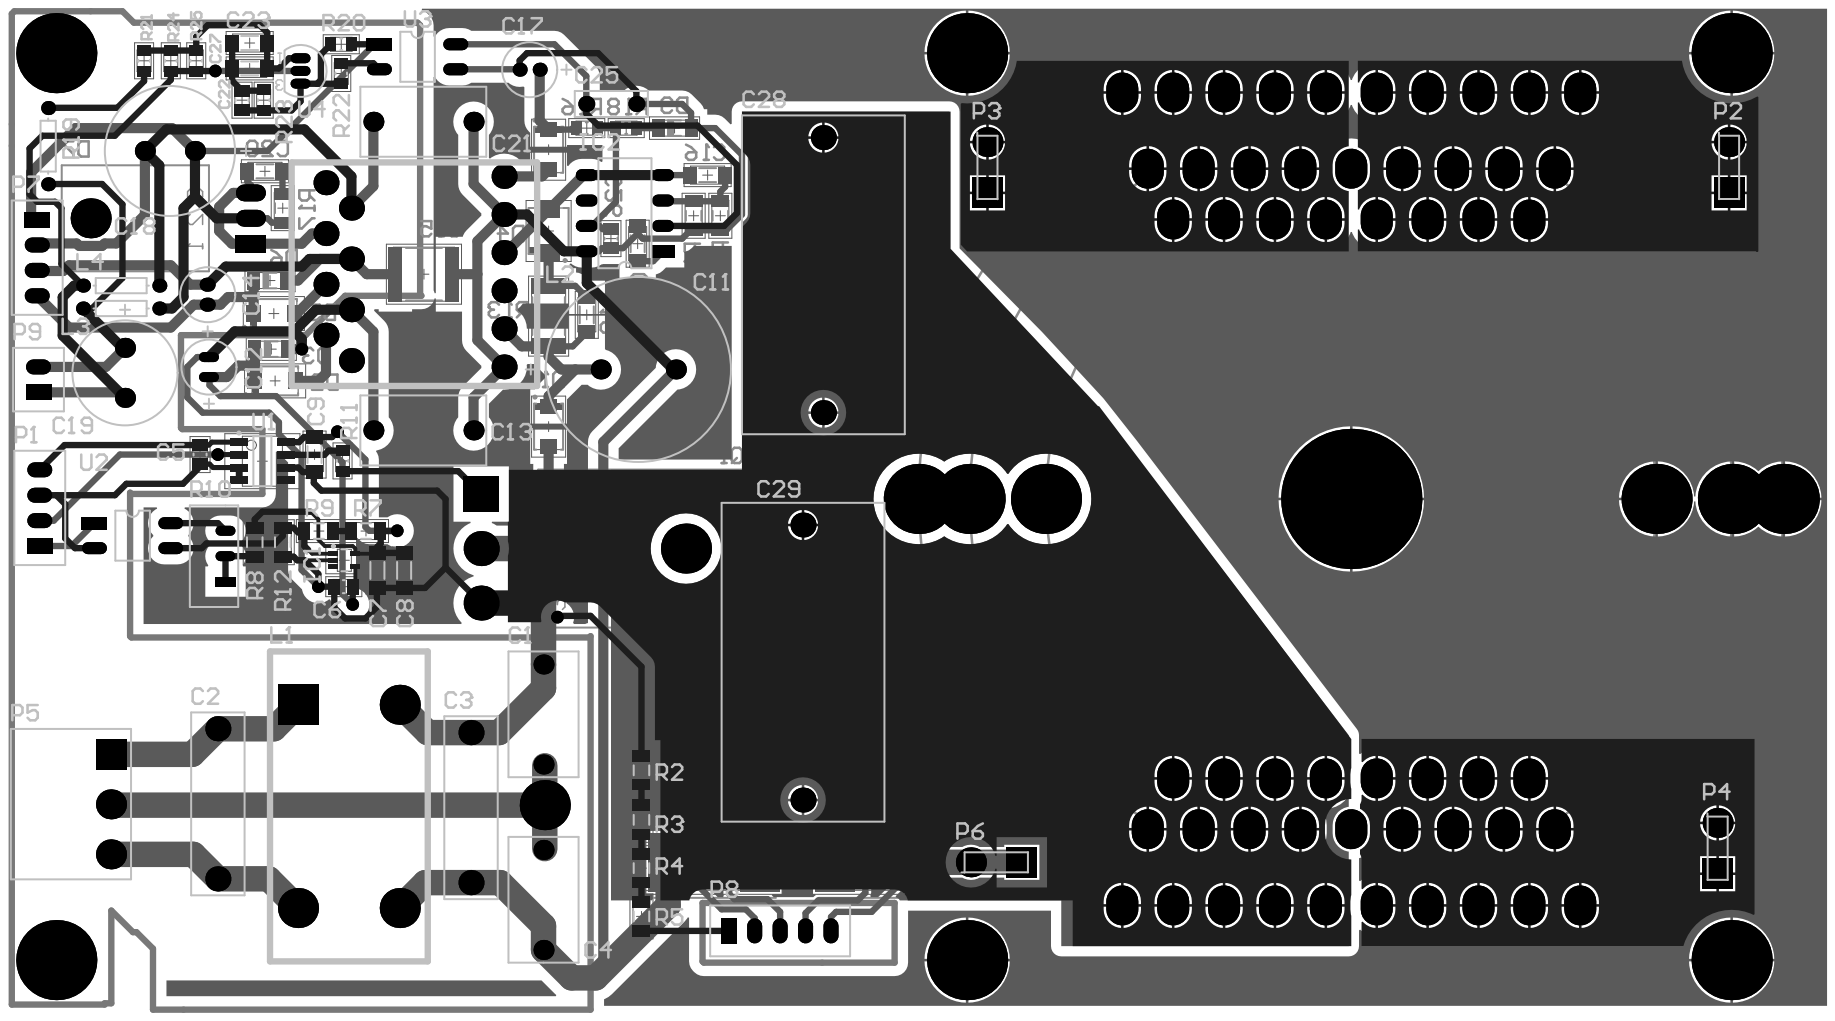
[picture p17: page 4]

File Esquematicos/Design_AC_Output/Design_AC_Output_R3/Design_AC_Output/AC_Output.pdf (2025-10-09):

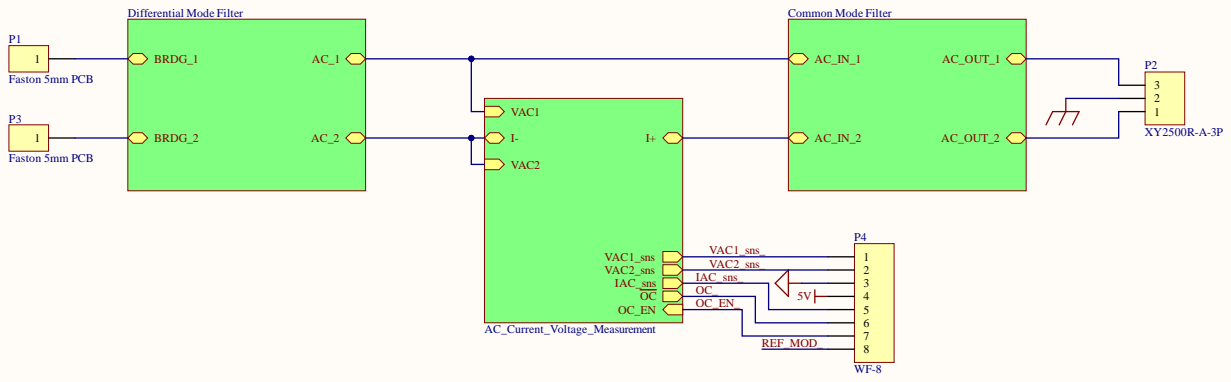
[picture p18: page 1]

IAC_ s n s _
O C_

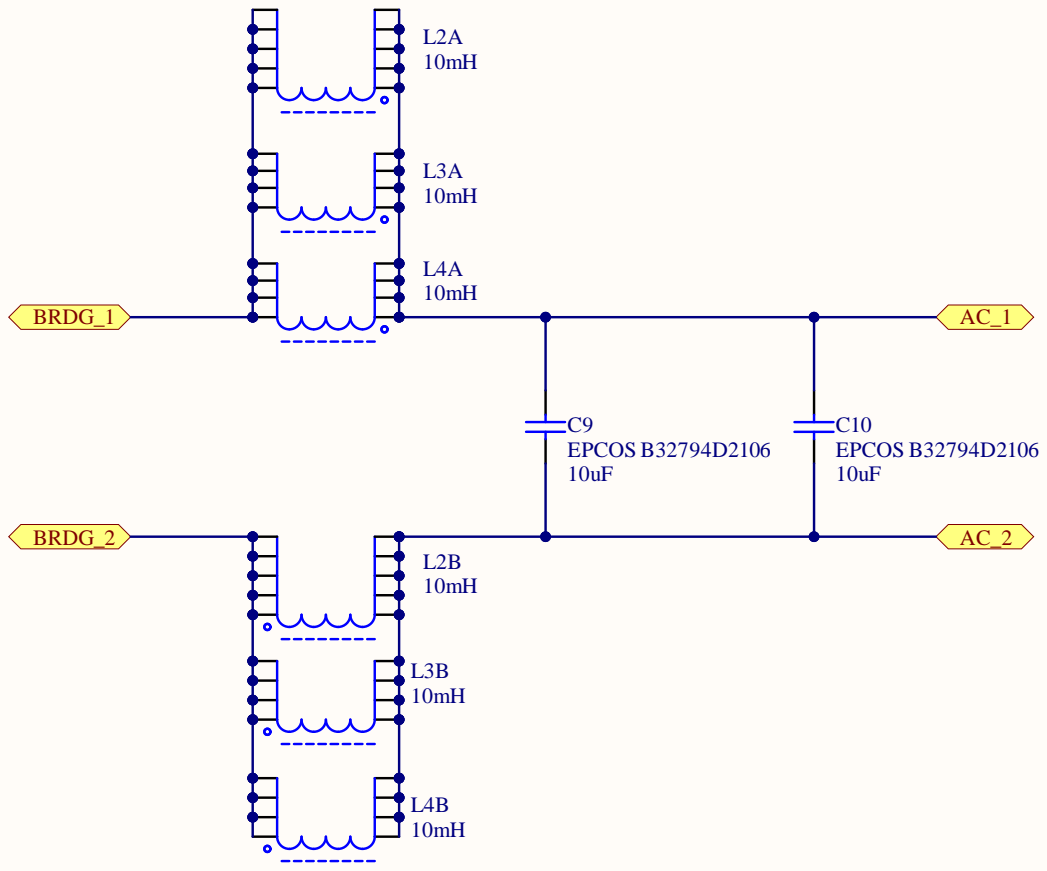
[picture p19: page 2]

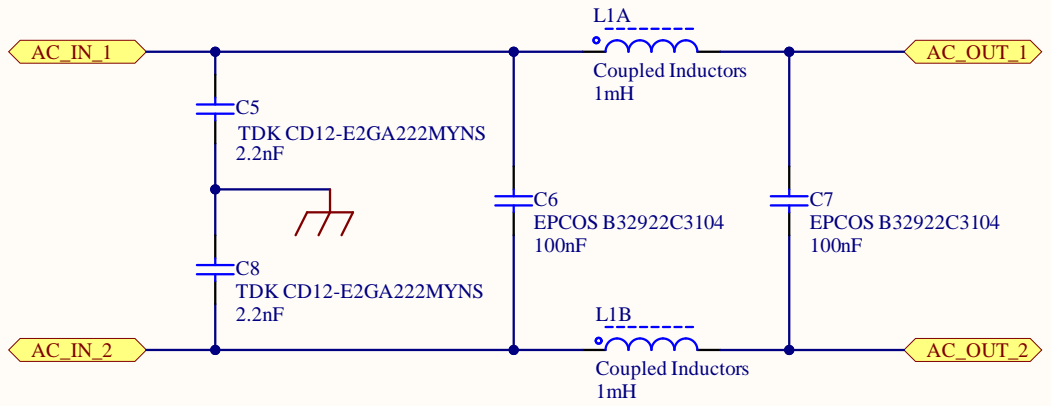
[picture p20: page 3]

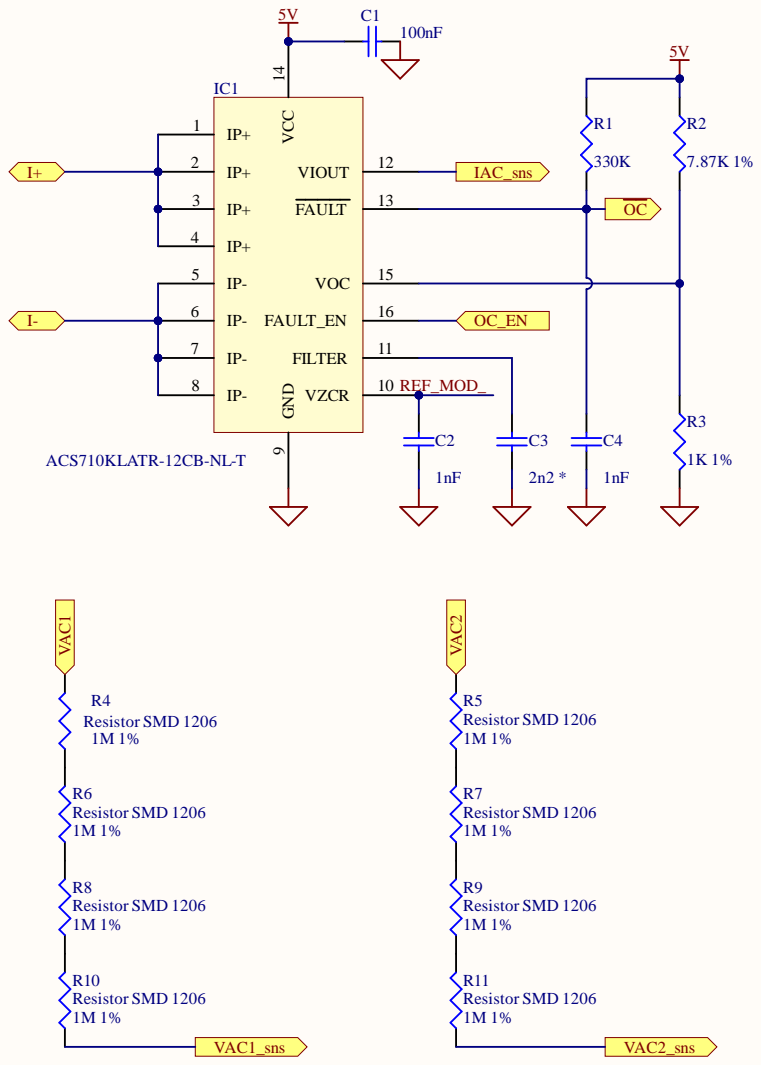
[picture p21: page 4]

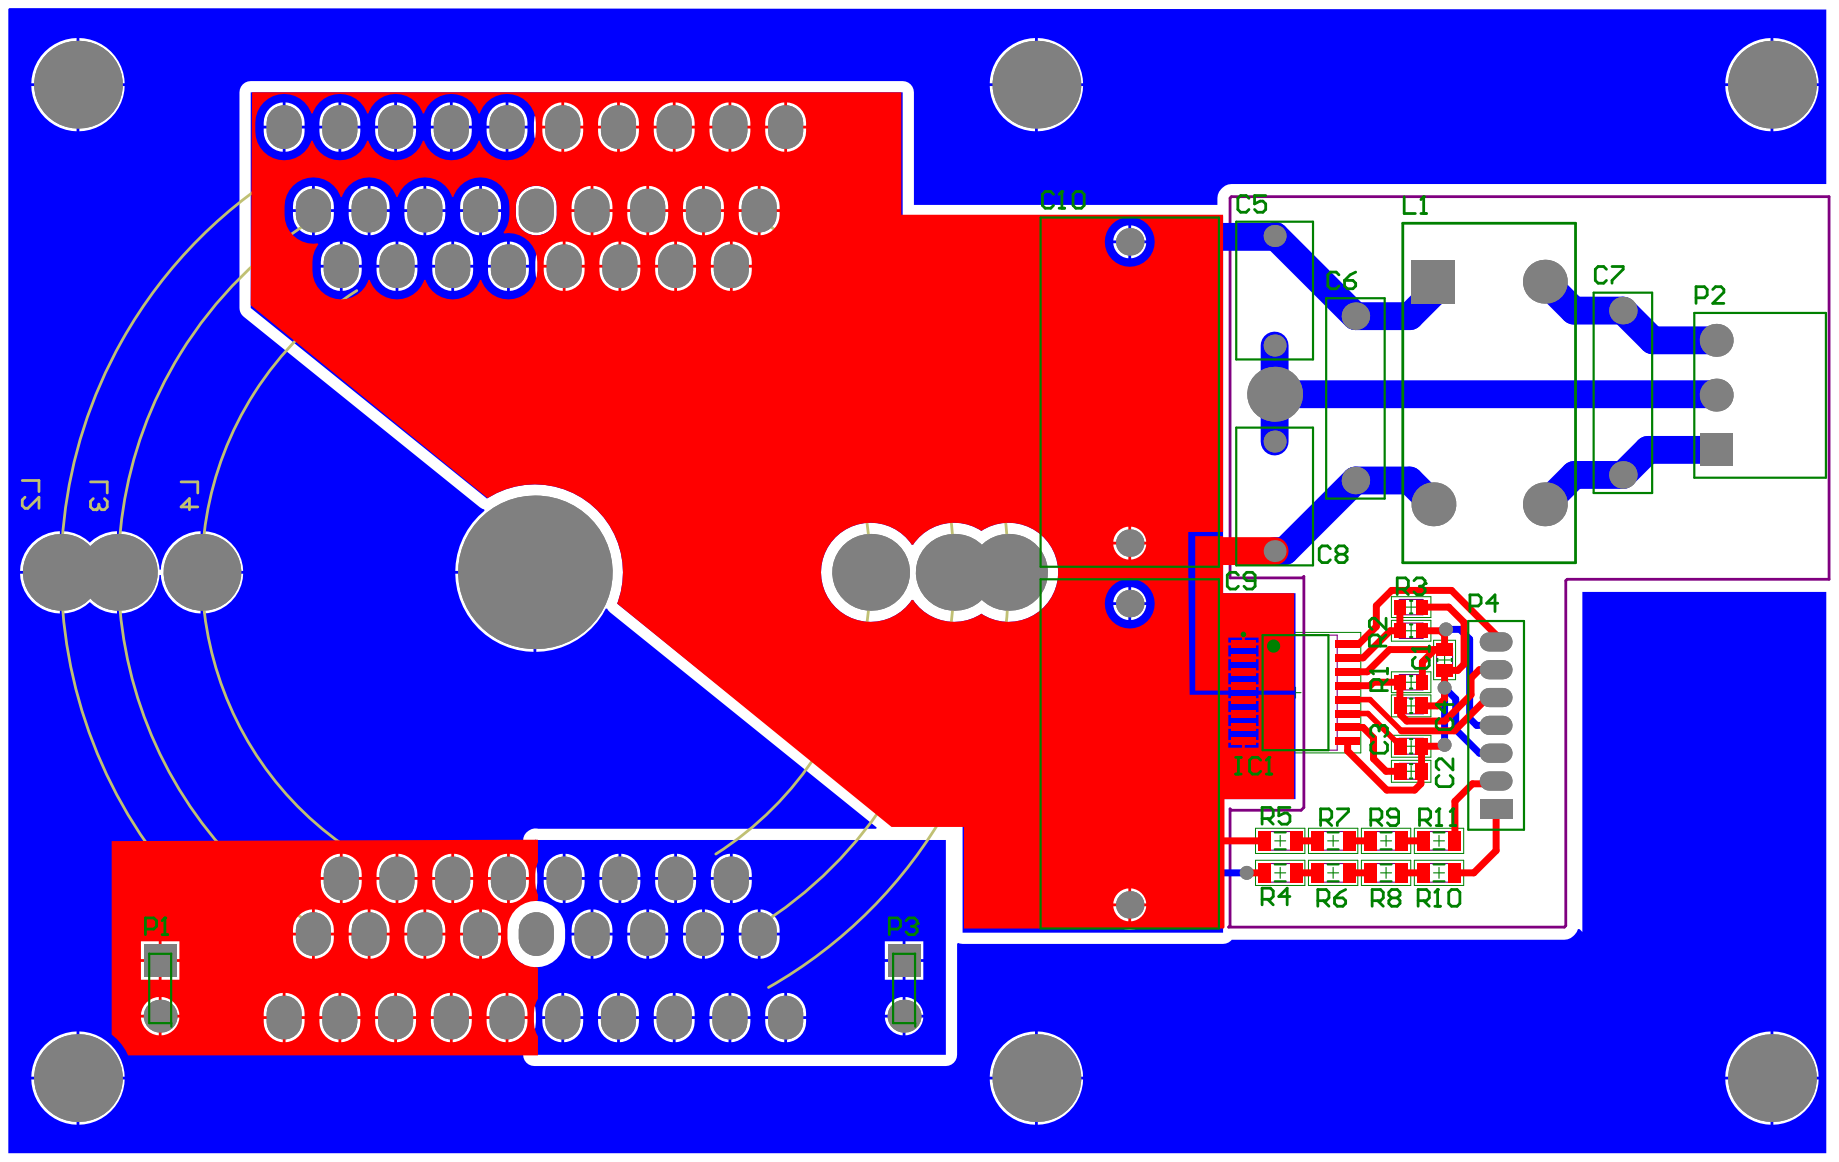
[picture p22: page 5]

Comment | Description | Value | Quantity | Designator
Resistor SMD 1206 | Resistor SMD 1206 | 1M 1% | 8 R4, R5, R6, R7, R8, R9, R10, R11
Coupled Inductors | Coupled Inductors with Ferrite core and Air gap | 10mH | 3 L2, L3, L4
EPCOS B32794D2106 | MKP AC Filtering 10uF 630Vdc | 10uF | 2 C9, C10
EPCOS B32922C3104 | MKP EMI suppression X2 100nF 305Vac | 100nF | 2 C6, C7
EPCOS B37940K51102J60 | Ceramic Multilayer 1nF 50Vdc COG | 1nF | 2 C2, C4
Faston 5mm PCB | Faston 5mm PCB | | 2 P1, P3
TDK CD12-E2GA222MYNS | Safety Standard Certified Ceramic Y1 2.2nF 250Vac | 2.2nF | 2 C5, C8
ACS710KLATR-12CB-NL-T | Hall Effect Current Sensor | | 1 IC1
Coupled Inductors | Bourns Common mode inductor 10A 1mH 8108-RC | 1mH | 1 L1
EPCOS B37940 | Ceramic Multilayer 50Vdc COG | 2n2 * | 1 C3
EPCOS C2012X7R1H104K | Ceramic Multilayer 100nF 50Vdc | 100nF | 1 C1
Resistor SMD 0805 | Resistor SMD 0805 | 1K 1% | 1 R3
Resistor SMD 0805 | Resistor SMD 0805 | 7.87K 1% | 1 R2
Resistor SMD 0805 | Resistor SMD 0805 | 330K | 1 R1
WF-8 | Header, 8-Pin | | 1 P4
XY2500R-A-3P | HEADER 3P 90gra P/CI P=5MM | | 1 P2

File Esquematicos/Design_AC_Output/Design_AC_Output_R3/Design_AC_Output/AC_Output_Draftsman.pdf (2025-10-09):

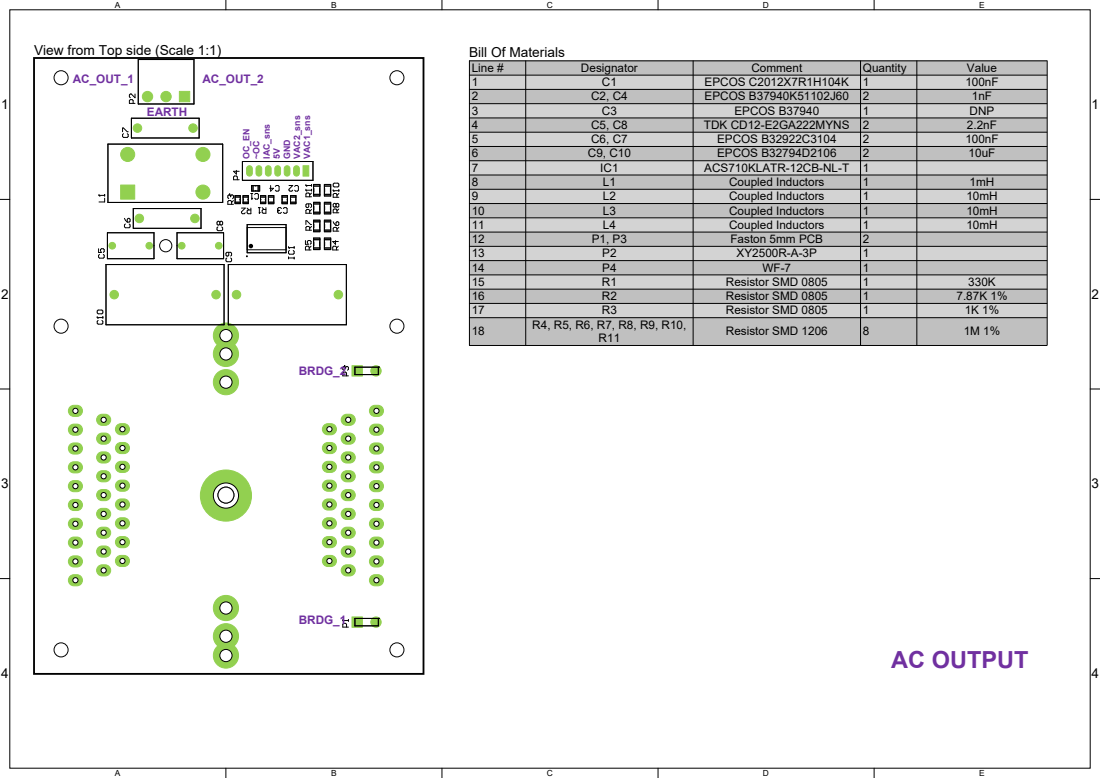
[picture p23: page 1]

View from Top side (Scale 1:1)

Line # | Designator | Comment | Quantity | Value
1 | C1 | EPCOS C2012X7R1H104K | 1 | 100nF
2 | C2, C4 | EPCOS B37940K51102J60 | 2 | 1nF

4 | C5, C8 | TDK CD12-E2GA222MYNS | 2 | 2.2nF
5 | C6, C7 | EPCOS B32922C3104 | 2 | 100nF
6 | C9, C10 | EPCOS B32794D2106 | 2 | 10uF
7 | IC1 | ACS710KLATR-12CB-NL-T | 1
8 | L1 | Coupled Inductors | 1 | 1mH
9 | L2 | Coupled Inductors | 1 | 10mH
10 | L3 | Coupled Inductors | 1 | 10mH
11 | L4 | Coupled Inductors | 1 | 10mH
12 | P1, P3 | Faston 5mm PCB | 2
13 | P2 | XY2500R-A-3P | 1
14 | P4 | WF-7 | 1
15 | R1 | Resistor SMD 0805 | 1 | 330K
16 | R2 | Resistor SMD 0805 | 1 | 7.87K 1%
17 | R3 | Resistor SMD 0805 | 1 | 1K 1%
18 | R4, R5, R6, R7, R8, R9, R10, R11 | Resistor SMD 1206 | 8 | 1M 1%

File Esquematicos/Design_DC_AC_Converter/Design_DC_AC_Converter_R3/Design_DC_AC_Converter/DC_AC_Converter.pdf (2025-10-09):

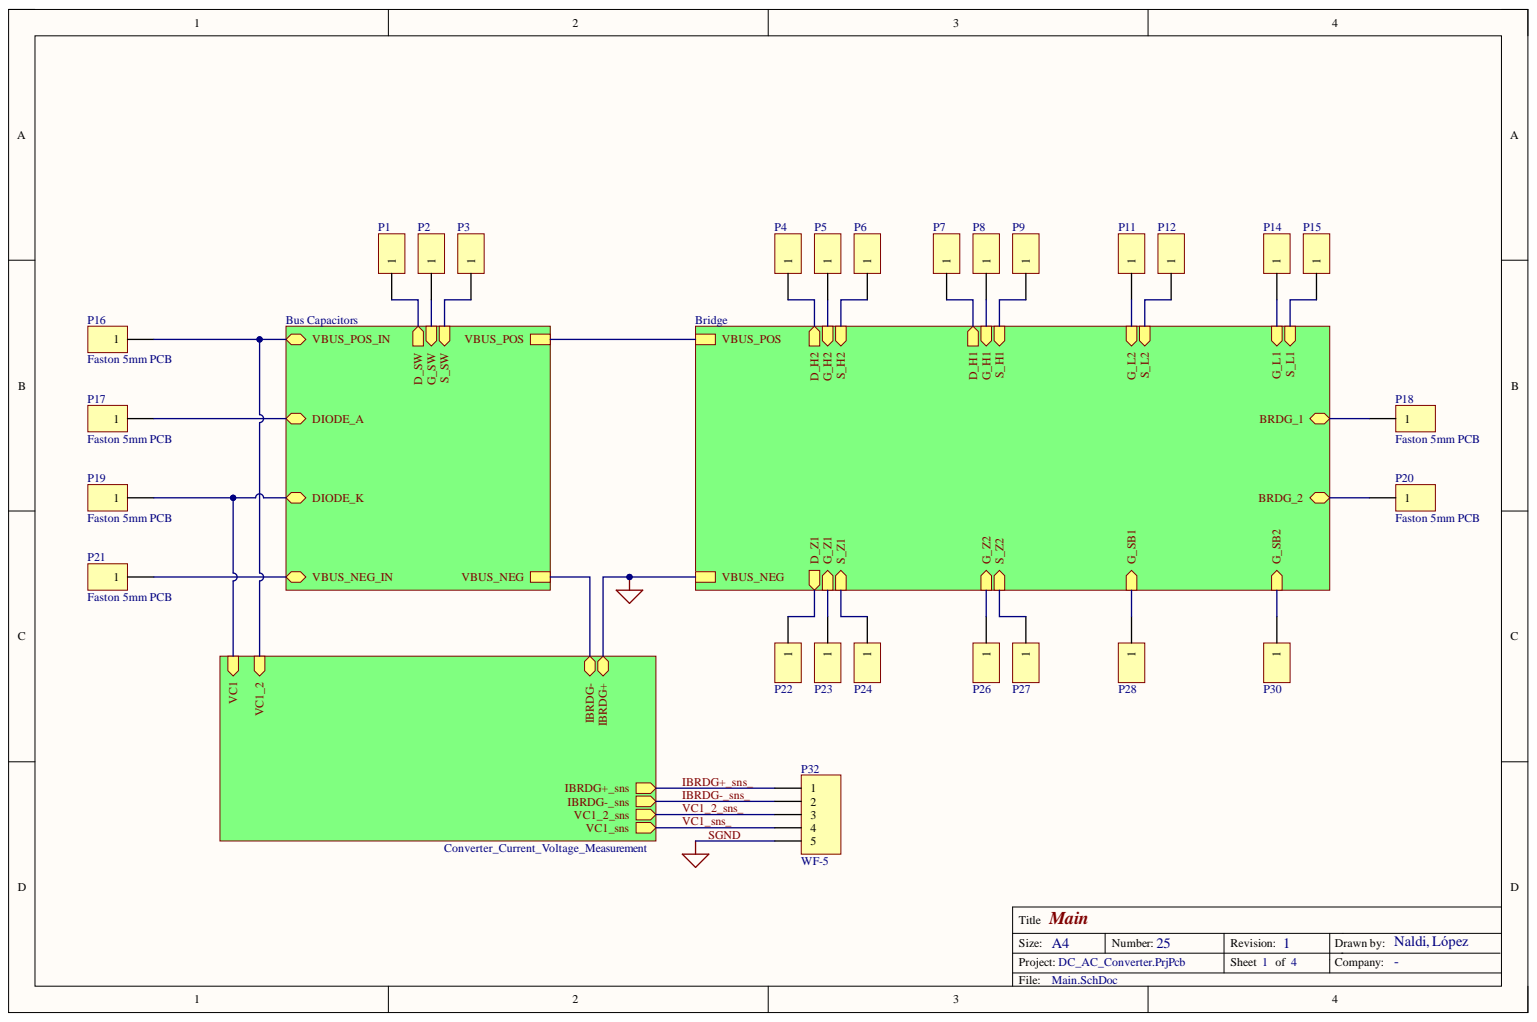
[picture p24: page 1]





Comment | Description | Value | Quantity | Designator
THT | Resistor | 1 MOhm - 1/4 W | 20 R20, R21, R22, R23, R24, R25, R26, R27, R28, R29, R31, R32, R33, R34, | R35, R36, R37, R38, R39, R40
TS-101-T-AA | Terminal Strip, 1-Pin, 2.54mm pitch | | 20 P1, P2, P3, P4, P5, P6, P7, P8, P9, P11, P12, P14, P15, P22, P23, P24, | P26, P27, P28, P30
5KP85A | Zener Diode | | 10 D3, D4, D5, D6, D7, D8, D9, D10, D11, D12
EPCOS B32778G4107 | MKP DC link - High density series - 100uF 450V | 100uF | 10 C7, C8, C9, C10, C11, C14, C15, C16, C17, C18
CRCW060310K0FKEA | Resistor | 10 kOhm - 1/10 W | 9 R10, R11, R12, R13, R16, R17, R18, R19, R30
Resistor SMD 1206 | Resistor SMD 1206 | 0R | 8 R2, R3, R4, R5, R6, R7, R8, R9
IKW20N60T, DNP | IGBTs LOW LOSS DuoPack 600V 20A | | 7 Q1, Q2, Q5, Q6, Q7, Q8, Q9
Faston 5mm PCB | Faston 5mm PCB | | 6 P16, P17, P18, P19, P20, P21
MURATA GA355QR7GF222KW01L | Safety Standard Certified Ceramic Y2 2.2nF 250Vac | 2.2nF | 4 C1, C2, C5, C6
CRCW060310K0FKEA | Resistor | 3.9 kOhm - 1/10 W | 2 R14, R15
EPCOS B32652A0103 | MKP High pulse (wound) 10nF 1000Vdc | 10nF | 2 C13, C20
EPCOS B32652A6104 | MKP High pulse (wound) 100nF 630Vdc | 100nF | 2 C3, C4
EPCOS B32654A6105 | MKP High pulse (wound) 1uF 630Vdc | 1uF | 2 C12, C19
IPD65R950CFD | MOSFET N-Ch 700V 3.9A DPAK-2 | | 2 Q3, Q4
MUR460 | Default Diode | | 2 D1, D2
Shunt Resistor Kelvin | Shunt Resistor Kelvin | 20m | 1 R1
WF-5 | Header, 5-Pin, 2.54mm pitch | | 1 P32

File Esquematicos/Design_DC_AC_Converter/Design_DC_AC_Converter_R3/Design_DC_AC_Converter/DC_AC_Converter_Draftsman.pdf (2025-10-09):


View from Top side (Scale 1:2)

Line # 123456789 | C7, C8, C9, C10, C11, C14, C15, C16, C17, C18 | EPCOS B32778G4107 | 1022 | 100uF

Designator | Comment | | Value
C1, C2, C5, C6 | MURATA GA355QR7GF222KW01L | Quantity 42 | 2.2nF

C3, C4 | EPCOS B32652A6104 | | 100nF

C12, C19 | EPCOS B32654A6105 | | 1uF
C13, C20 | EPCOS B32652A0103 | | 10nF

P1, P2, P3, P4, P5, P6, P7, P8, P9, P11, P12, P14, P15, P22, P23, P24, P26, P27, P28, P30 | TS-101-T-AA
P16, P17, P18, P19, P20, P21 | Faston 5mm PCB | 20617218

Q1, Q2, Q5, Q6, Q7, Q8, Q9 | IPx65R110CFD

10 | Q3, Q4 | IPD65R950CFD
11 | R1 | Shunt Resistor Kelvin | | 20m
12 | R2, R3, R4, R5, R6, R7, R8, R9 | Resistor SMD 1206 | | 1 M 1%

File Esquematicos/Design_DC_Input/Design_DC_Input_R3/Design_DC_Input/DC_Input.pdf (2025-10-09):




Comment | Description | Value | Quantity | Designator
Faston 5mm PCB | Faston 5mm PCB | | 4 P2, P3, P4, P6
Resistor SMD 1206 | Resistor SMD 1206 | 0R | 4 R2, R3, R4, R5
TDK CD12-E2GA222MYNS | Safety Standard Certified Ceramic Y1 2.2nF 250Vac | 2.2nF | 4 C1, C4, C13, C21
Coupled Inductors | Coupled Inductors with Ferrite core and Air gap | 10mH | 3 L5, L6, L7
EPCOS B41827A6226M000 | ALUMINUM ELECTROLYTIC 22UFX50V | 22uF | 3 C12, C14, C17
ES1D | Ultrafast rectifier 1A 200V | | 3 D2, D5, D8
BZV55C15V | Zener Diode 15V 0.5W | | 2 D3, D6
EPCOS B32794D2106 | MKP AC Filtering 10uF 630Vdc | 10uF | 2 C28, C29
EPCOS B32922C3104 | MKP EMI suppression X2 100nF 305Vac | 100nF | 2 C2, C3
EPCOS B37872K5223K60 | Ceramic Multilayer 22nF 50Vdc X7R | 22nF | 2 C20, C23
EPCOS CL31B473KBCNNNC | Ceramic Multilayer 47nF 50Vdc X7R | 47nF | 2 C24, C27
Resistor SMD 0805 | Resistor SMD 0805 | 1K | 2 R21, R23
Resistor SMD 1206 | Resistor SMD 1206 | 1R3 1% | 2 R14, R15
Shunt Resistor Kelvin | Shunt Resistor Kelvin | 20m | 2 R1, R6
2 Primary, 3 Secondary, Shield | Coupled Inductors with Ferrite Core | | 1 L2
BZV55C22V | Zener Diode 22V 0.5W | | 1 D9
Coupled Inductors | Bourns Common mode inductor 10A 1mH 8108-RC | 1mH | 1 L1
EPCOS B32529C0102K000 | MKT General purpose 1nF 63Vdc | 1nF | 1 C25
EPCOS B37871K5221J60 | Ceramic Multilayer 50Vdc C0G | DNP | 1 C16
EPCOS B37940K51102J60 | Ceramic Multilayer 1nF 50Vdc COG | 1nF | 1 C22
EPCOS B41856A5108M000 | ALuminum Electrolytic Low Impedance 105 °C 1000uF x 25V | 1000uF | 1 C18
EPCOS B41856A5337M008 | ALuminum Electrolytic Low Impedance 105 °C 330uF x 25V | 330uF | 1 C19
EPCOS C2012X7R1H104K | Ceramic Multilayer 100nF 50Vdc X7R | 100nF | 1 C26
ICE3BR1765J | Off-Line SMPS Current Mode Controller with integrated 650V CoolMOS® and Startup cell (frequency jitter Mode) | | 1 IC2
IPx65R110CFD | Infineon Power MOSFET N-Channel 650V 31.2A | | 1 Q1
M7 | 1A 1000V SMA | | 1 D1
MURATA GA355QR7GF222KW01L | Safety Standard Certified Ceramic Y2 2.2nF 250Vac | 2.2nF | 1 C15
Resistor SMD 0805 | Resistor SMD 0805 | 1.2K | 1 R20
Resistor SMD 0805 | Resistor SMD 0805 | 18R | 1 R16
Resistor SMD 0805 | Resistor SMD 0805 | 20K | 1 R25
Resistor SMD 0805 | Resistor SMD 0805 | 47R | 1 R18
Resistor SMD 0805 | Resistor SMD 0805 | 430R | 1 R22
Resistor SMD 0805 | Resistor SMD 0805 | DNP | 1 R24
Resistor SMD 1206 | Resistor SMD 1206 | 1K | 1 R17
Resistor SMD 2512 | Resistor SMD 2512 1W | 1K | 1 R13
Resistor Through-hole | Resistor 1/4W 5% | 75K | 1 R19
RUBYCON 400BXC68MEFC18X25 | MINIATURE ALUMINUM ELECTROLYTIC 68uF 400V 105ºC | 68uF | 1 C11
SFH617A | Phototransistor Output, High Reliability, 5300 VRMS, 110 °C Rated | | 1 U3
STTH112 | High voltage ultrafast rectifier | | 1 D4
TDK C3216C0G2J222J115AA | Ceramic Multilayer 2.2nF 630Vdc COG | 2.2nF | 1 C10
TL431ACLP | Adjustable Precision Shunt Regulator | | 1 U4
V30100C | Trench MOS Barrier Schottky Rectifier 2x 15A 100V | | 1 D7
WF-2 | Header, 2-Pin, 2.54mm pitch | | 1 P9
WF-4 | Header, 4-Pin, 2.54mm pitch | | 1 P7
WF-5 | Header, 5-Pin, 2.54mm pitch | | 1 P8
XY2500R-A-3P | HEADER 3P 90gra P/CI P=5MM | | 1 P5

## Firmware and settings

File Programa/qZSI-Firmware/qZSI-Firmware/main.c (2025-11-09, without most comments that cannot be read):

/**
 * @file main.c
 * @brief Punto de entrada principal para el proyecto qZSI-Firmware.
 * @author Zuliani, Agustin
 * 
 * Este archivo contiene la función principal y las rutinas de servicio de interrupción (ISR)
 * para el proyecto qZSI-Firmware. Inicializa los periféricos y maneja el bucle principal de control.
 */

/*
 * Proyecto Final de Ing. Electronica - TM
 *
 * Copyright 2024, Guido Cicconi - Gustavo Garcia - Juan Tinazzo
 * All rights reserved.
 *
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
 * 3. Neither the name of the copyright holder nor the names of its
 *    contributors may be used to endorse or promote products derived from this
 *    software without specific prior written permission.
 *
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
 */

/**********************************************************************/

/*
 * NOTA: Este proyecto cuenta con dos linker scripts disponibles: Linker.cmd
 * y Linker_no_flash.cmd. Con el primero de ellos, el programa se carga
 * en la memoria flash del DSP, y permanece ante la falta de energ�a,
 * por lo que se comienza a ejecutar en cada arranque. Con el segundo,
 * el programa se carga en un sector de la memoria RAM, por lo que carece
 * de persistencia ante la falta de energ�a. Se recomienda utilizar este
 * �ltimo en el desarrollo, para evitar arranques indeseados del inversor.
 * Para utilizar uno u otro, basta con excluir de la compilaci�n al no
 * deseado, haciendo click derecho sobre el mismo y marcando la opci�n
 * "Exclude from Build".
 * Adem�s, si se desea utilizar la flash, se debe descomentar la l�nea
 * que define la macro USING_FLASH en el archivo Board_Init.h
 *
 */

/**********************************************************************
                             INCLUDES
**********************************************************************/
#include "DSP2833x_Device.h"
#include "DSP2833x_DefaultIsr.h"
#include "IQmathLib.h"
#include "DelayUs.h"

#include "Inits/Adc.h"
#include "Inits/EPwm.h"
#include "Inits/Dma.h"
#include "Inits/CpuTimers.h"
#include "Inits/Board_Init.h"
#include "Inverter/qZSI.h"
#include "MEFs/mefPrincipal.h"
#include "board.h"
#include "Drivers/digitalPot.h"
#include "Drivers/key.h"
#include "Drivers/LedIndicator.h"
#include "Inverter/inverterConfig.h"
#include "Test/DataLogger.h"

/**********************************************************************
                              DEFINES
**********************************************************************/
#define CORE_CLOCK_FREQ             150E6
#define SYSTICK_PERIOD              1E-3
#define DATA_LOGGER_TRIGGER_VALUE   DC_BUS_VOLTAGE_REFERENCE/3
#define DATA_LOGGER_PRE_SCALAR      0

/**********************************************************************
                      VARIABLES DECLARATION
**********************************************************************/
/*
 * El m�dulo DMA guarda autom�ticamente las mediciones del ADC en el
 * buffer AdcBuff. Con esta instrucci�n se fuerza al compilador a
 * ubicar al buffer en una secci�n de la RAM accesible por DMA,
 * llamada dmaMemBufs y definida en el linker script.
 *
 */
#pragma DATA_SECTION(AdcBuff, "dmaMemBufs");
volatile Uint16 AdcBuff[ADC_total], AdcBuff2[ADC_total];
volatile dataLogger_t dLogValues = {0, 0, 0, 0};

/**********************************************************************
                      FUNCTIONS DEFINITIONS
**********************************************************************/

/**
 * @brief Función principal para el proyecto qZSI-Firmware.
 * 
 * Inicializa la placa, los periféricos y las variables globales. Ejecuta constantemente
 * la máquina de estados principal (mefPrincipal) que contiene submáquinas de estados.
 */
void main(void){

    // -- Buffers init
    int iloop;
    for(iloop = 0; iloop<ADC_total; iloop++){
        AdcBuff[iloop] = 0;
        AdcBuff2[iloop] = 0;
    }

    //--- Some board functions initialization
    BoardInit();

    //--- Peripheral Initialization
    InitAdc();                                      // Initialize the ADC (FILE: Adc.c)
    InitEPwm();                                     // Initialize the EPwm (FILE: EPwm.c)
    InitDma(AdcBuff);                               // Initialize the DMA (FILE: Dma.c)
    InitTimers(CORE_CLOCK_FREQ, SYSTICK_PERIOD);    // Initialize the CPU Timer 0 to interrupt every 1ms (FILE: CpuTimers.c)

    //--- Initialize the shared GPIO pins (FILE: Gpio.c)
    InitGpio();

    //--- Initialize the voltage references for hardware protections
    digitalPot_configureReferences();

    //--- Other Initializations
    key_init();
    qzsi_init();
    mefPrincipal_init();
    ledIndicator_init();
    dataLoggerReset(DATA_LOGGER_TRIGGER_VALUE,
                    DATA_LOGGER_PRE_SCALAR);

    //--- Enable global interrupts
    asm(" CLRC INTM, DBGM");                        // Enable global interrupts and realtime debug

    //--- Main Loop
	while(1)
	{
	    mefPrincipal();
	}
}

/**
 * @brief ISR para la interrupción del temporizador 0 de la CPU (SysTick).
 * 
 * Configura el temporizador para interrumpirse cada 1 ms. Dentro de esta función
 * se monitorean distintos periféricos y se actualizan variables.
 */
void TINT0_ISR(void){                 // PIE1.7 @ 0x000D4C  TINT0 (CPU TIMER 0)
    PieCtrlRegs.PIEACK.all = PIEACK_GROUP1;     // Must acknowledge the PIE group
    CpuTimer0Regs.TCR.bit.TIF = 1;              // Clear flag

    mefPrincipal_task1ms();
    key_periodicTask1ms();
    qzsi_task1ms();
    ledIndicator_task1ms();
}

/**
 * @brief ISR para la interrupción del EPWM6.
 * 
 * Esta ISR maneja los algoritmos de control para el inversor qZSI. Procesa
 * los datos del ADC, aplica los lazos de control y actualiza las salidas PWM.
 */
void EPWM6_INT_ISR(void){             // PIE3.6 @ 0x000D6A  EPWM6_INT (EPWM6)
    PieCtrlRegs.PIEACK.all = PIEACK_GROUP3;     // Must acknowledge the PIE group
    EPwm6Regs.ETCLR.bit.INT = 1;                // Clear flag

    // Crea las variables de manera estatica (se mantienen entre cada llamada)
    static activeVars_t activeVars = {0, 0, 0, 0, 0};
    static stVars_t stVars = {0, 0, 0, 0};
    static _iq d0 = 0, D = 0;

    // Se copian a AdcBuff2 las variables muestreadas por el ADC almacenadas por DMA en AdcBuff
    memcpy(&AdcBuff2, &AdcBuff, sizeof(AdcBuff));

    // Calculo de las variables --> Para vector activo y shoot-through
    qzsi_calculateVariables(&activeVars, &stVars, AdcBuff2);

    // Cargamos datos en el Data Logger
    dLogValues.ch_val1 = activeVars.VDC;
    dLogValues.ch_val2 = activeVars.Vac;
    dLogValues.ch_val3 = stVars.IL;
    dLogValues.ch_val4 = stVars.IL1;

    dataLoggerRun(&dLogValues);


    #if SOFTWARE_PROTECTIONS == 1
    if((!qzsi_hardwareReady() /*|| qzsi_softProtection(stVars.IL1, stVars.Iin, activeVars.VC1, activeVars.Vac, activeVars.Iac)*/) && !mefPrincipal_getFalla()){
        mefPrincipal_setFalla();
        epwm_softOneShotTZ();
    }
    #endif

    if(mefPrincipal_getArranqueVBUS()){                                                       // En el arranque no se utilizan los lazos de control
        d0 = qzsi_getOpenLoop_d0(OPEN_LOOP_VIN);
    }
    else{
        #if BUS_VOLTAGE_CLOSED_LOOP
        d0 = qzsi_dcBusController(stVars.IL, activeVars.VDC, _IQmpy(activeVars.IBRDG, D), stVars.Vin);   // IDC = IBRDG muestreada en el medio del vector activo * D
        #else
        d0 = qzsi_getOpenLoop_d0(OPEN_LOOP_VIN);
        #endif
    }

    if(mefPrincipal_getArranqueVO()){                                                         // En el arranque no utilizan los lazos de control
        D = qzsi_getOpenLoop_D();
        qzsi_outputVoltageController(activeVars.Vac, activeVars.IBRDG);                       // Se llama al controlador para actualizar los valores iniciales
    }
    else{
        #if OUTPUT_VOLTAGE_CLOSED_LOOP == 1
        D = qzsi_outputVoltageController(activeVars.Vac, activeVars.IBRDG);
        #else
        D = qzsi_getOpenLoop_D();
        #endif
    }

    if(d0 > 1-_IQabs(D)) d0 = 1-_IQabs(D);

    qzsi_updatePWM(d0, D);
    qzsi_updateSineReference();
}

/**
 * @brief ISR para la interrupción de zona de fallo del EPWM6.
 * 
 * Esta ISR se activa cuando se detecta una condición de fallo en el módulo EPWM6.
 * Establece la bandera de fallo y desactiva las salidas del inversor.
 */
void EPWM6_TZINT_ISR(void){                     // PIE2.6 @ 0x000D5A  EPWM6_TZINT (EPWM6)
    PieCtrlRegs.PIEACK.all = PIEACK_GROUP2;     // Must acknowledge the PIE group
    mefPrincipal_setFalla();
}

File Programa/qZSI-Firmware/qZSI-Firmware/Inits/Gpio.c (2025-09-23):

/*
 * Proyecto Final de Ing. Electronica - TM
 *
 * Copyright 2024, Guido Cicconi - Gustavo Garcia - Juan Tinazzo
 * All rights reserved.
 *
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
 * 3. Neither the name of the copyright holder nor the names of its
 *    contributors may be used to endorse or promote products derived from this
 *    software without specific prior written permission.
 *
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
 */

/**********************************************************************
                             INCLUDES
**********************************************************************/
#include "Gpio.h"

/**********************************************************************
                   EXTERNAL FUNCTIONS DEFINITION
**********************************************************************/

/**********************************************************************
* Function: InitGpio()
*
* Description: Initializes the shared GPIO pins on the F2833x
**********************************************************************/
extern void InitGpio(void){
	asm(" EALLOW");								// Enable EALLOW protected register access

	//--- Group A pins
	GpioCtrlRegs.GPACTRL.all  = 0x00000000;		// QUALPRD = SYSCLKOUT for all group A GPIO
	GpioCtrlRegs.GPAQSEL1.all = 0x00000000;		// No qualification for all group A GPIO 0-15
	GpioCtrlRegs.GPAQSEL2.all = 0x00000000;		// No qualification for all group A GPIO 16-31
	GpioCtrlRegs.GPADIR.all   = 0x00000000;		// All group A GPIO are inputs
	GpioCtrlRegs.GPAPUD.all   = 0xFFFFFFFF;		// All group A pullups disabled

	GpioCtrlRegs.GPAMUX1.bit.GPIO0  = 1;		// 0=GPIO  1=EPWM1A     2=rsvd       3=rsvd
	GpioCtrlRegs.GPAMUX1.bit.GPIO1  = 1;		// 0=GPIO  1=EPWM1B     2=ECAP6      3=rsvd
	GpioCtrlRegs.GPAMUX1.bit.GPIO2  = 1;		// 0=GPIO  1=EPWM2A     2=rsvd       3=rsvd
	GpioCtrlRegs.GPAMUX1.bit.GPIO3  = 1;		// 0=GPIO  1=EPWM2B     2=ECAP5      3=rsvd
	GpioCtrlRegs.GPAMUX1.bit.GPIO4  = 1;		// 0=GPIO  1=EPWM3A     2=rsvd       3=rsvd
	GpioCtrlRegs.GPAMUX1.bit.GPIO5  = 1;		// 0=GPIO  1=EPWM3B     2=MFSRA      3=ECAP1
	GpioCtrlRegs.GPAMUX1.bit.GPIO6  = 1;		// 0=GPIO  1=EPWM4A     2=EPWMSYNCI  3=EPWMSYNCO
	GpioCtrlRegs.GPAMUX1.bit.GPIO7  = 1;		// 0=GPIO  1=EPWM4B     2=MCLKRA     3=ECAP2
	GpioCtrlRegs.GPAMUX1.bit.GPIO8  = 0;		// 0=GPIO  1=EPWM5A     2=CANTXB     3=ADCSOCAO
	GpioCtrlRegs.GPAMUX1.bit.GPIO9  = 1;		// 0=GPIO  1=EPWM5B     2=SCITXDB    3=ECAP3
	GpioCtrlRegs.GPAMUX1.bit.GPIO10 = 0;		// 0=GPIO  1=EPWM6A     2=CANRXB     3=ADCSOCBO
	GpioCtrlRegs.GPAMUX1.bit.GPIO11 = 0;		// 0=GPIO  1=EPWM6B     2=SCIRXDB    3=ECAP4
	GpioCtrlRegs.GPAMUX1.bit.GPIO12 = 0;		// 0=GPIO  1=TZ1        2=CANTXB     3=SPISIMOB
	GpioCtrlRegs.GPAMUX1.bit.GPIO13 = 0;		// 0=GPIO  1=TZ2        2=CANRXB     3=SPISOMIB
	GpioCtrlRegs.GPAMUX1.bit.GPIO14 = 0;		// 0=GPIO  1=TZ3/XHOLD  2=SCITXDB    3=SPICLKB
	GpioCtrlRegs.GPAMUX1.bit.GPIO15 = 0;		// 0=GPIO  1=TZ4/XHOLDA 2=SCIRXDB    3=SPISTEB

	GpioCtrlRegs.GPAMUX2.bit.GPIO16 = 3;		// 0=GPIO  1=SPISIMOA   2=CANTXB     3=TZ5
	GpioCtrlRegs.GPAMUX2.bit.GPIO17 = 0;		// 0=GPIO  1=SPISOMIA   2=CANRXB     3=TZ6
	GpioCtrlRegs.GPAMUX2.bit.GPIO18 = 0;		// 0=GPIO  1=SPICLKA    2=SCITXDB    3=CANRXA
	GpioCtrlRegs.GPAMUX2.bit.GPIO19 = 0;		// 0=GPIO  1=SPISTEA    2=SCIRXDB    3=CANTXA
	GpioCtrlRegs.GPAMUX2.bit.GPIO20 = 0;		// 0=GPIO  1=EQEP1A     2=MDXA       3=CANTXB
	GpioCtrlRegs.GPAMUX2.bit.GPIO21 = 0;		// 0=GPIO  1=EQEP1B     2=MDRA       3=CANRXB
	GpioCtrlRegs.GPAMUX2.bit.GPIO22 = 0;		// 0=GPIO  1=EQEP1S     2=MCLKXA     3=SCITXDB
	GpioCtrlRegs.GPAMUX2.bit.GPIO23 = 0;		// 0=GPIO  1=EQEP1I     2=MFSXA      3=SCIRXDB
	GpioCtrlRegs.GPAMUX2.bit.GPIO24 = 0;		// 0=GPIO  1=ECAP1      2=EQEP2A     3=MDXB
	GpioCtrlRegs.GPAMUX2.bit.GPIO25 = 0;		// 0=GPIO  1=ECAP2      2=EQEP2B     3=MDRB
	GpioCtrlRegs.GPAMUX2.bit.GPIO26 = 0;		// 0=GPIO  1=ECAP3      2=EQEP2I     3=MCLKXB
	GpioCtrlRegs.GPAMUX2.bit.GPIO27 = 0;		// 0=GPIO  1=ECAP4      2=EQEP2S     3=MFSXB  
	GpioCtrlRegs.GPAMUX2.bit.GPIO28 = 1;		// 0=GPIO  1=SCIRXDA    2=XZCS6      3=XZCS6
	GpioCtrlRegs.GPAMUX2.bit.GPIO29 = 1;		// 0=GPIO  1=SCITXDA    2=XA19       3=XA19
	GpioCtrlRegs.GPAMUX2.bit.GPIO30 = 1;		// 0=GPIO  1=CANRXA     2=XA18       3=XA18
	GpioCtrlRegs.GPAMUX2.bit.GPIO31 = 1;		// 0=GPIO  1=CANTXA     2=XA17       3=XA17

	//--- Group B pins
	GpioCtrlRegs.GPBCTRL.all  = 0x00000000;		// QUALPRD = SYSCLKOUT for all group B GPIO
	GpioCtrlRegs.GPBQSEL1.all = 0x00000000;		// No qualification for all group B GPIO 32-47
	GpioCtrlRegs.GPBQSEL2.all = 0x00000000;		// No qualification for all group B GPIO 48-63
	GpioCtrlRegs.GPBDIR.all   = 0x00000000;		// All group B GPIO are inputs
	GpioCtrlRegs.GPBPUD.all   = 0xFFFFFFFF;		// All group B pullups disabled
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

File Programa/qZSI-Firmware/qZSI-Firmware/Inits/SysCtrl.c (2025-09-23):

/**********************************************************************
* File: SysCtrl.c
* Devices: TMS320F2833x
* Author: Technical Training Organization (TTO), Texas Instruments
* History:
*   07/15/08 - original
**********************************************************************/

/**********************************************************************
                             INCLUDES
**********************************************************************/
#include "SysCtrl.h"
#include "../DelayUs.h"

/**********************************************************************
                   EXTERNAL FUNCTIONS DEFINITION
**********************************************************************/

/**********************************************************************
* Function: InitSysCtrl()
*
* Description: Initializes the F2833x CPU
**********************************************************************/
extern void InitSysCtrl(void)
{
    volatile Uint16 i;						// General purpose Uint16
    volatile int16 dummy;					// General purpose volatile int16

	asm(" EALLOW");						// Enable EALLOW protected register access

	//--- Memory Protection Configuration
	DevEmuRegs.PROTSTART = 0x0100;		// Write default value to protection start register
	DevEmuRegs.PROTRANGE = 0x00FF;		// Write default value to protection range register

	//--- Configure the PLL

	// Note: The DSP/BIOS configuration tool can also be used to initialize the PLL
	// instead of doing the initialization here.

	// Make sure the PLL is not running in limp mode
	if (SysCtrlRegs.PLLSTS.bit.MCLKSTS != 1)
	{													// PLL is not running in limp mode
		SysCtrlRegs.PLLSTS.bit.MCLKOFF = 1;				// Turn off missing clock detect before changing PLLCR
		SysCtrlRegs.PLLSTS.bit.DIVSEL = 0;				// DIVSEL must be 0 or 1  (/4 CLKIN mode) before changing PLLCR
		SysCtrlRegs.PLLCR.bit.DIV = 0x000A;				// PLLx10/4 (because DIVSEL is /4)
   
		// Wait for PLL to lock.
		// During this time the CPU will run at OSCCLK/2 until the PLL is stable.
		// Once the PLL is stable the CPU will automatically switch to the new PLL value.
		// Code is not required to sit and wait for the PLL to lock.  However, 
		// if the code does anything that is timing critical (e.g. something that
		// relies on the CPU clock frequency to be at speed), then it is best to wait
		// until PLL lock is complete.  The watchdog should be disabled before this loop
		// (e.g., as was done above), or fed within the loop.
		while(SysCtrlRegs.PLLSTS.bit.PLLLOCKS != 1)		// Wait for PLLLOCKS bit to set
		{
			SysCtrlRegs.WDKEY = 0x0055;					// Service the watchdog while waiting
			SysCtrlRegs.WDKEY = 0x00AA;					//   in case the user enabled it.
		}

		// After the PLL has locked, we are running in PLLx10/4 mode (since DIVSEL is /4).
		// We can now enable the missing clock detect circuitry, and also change DIVSEL
		// to /2.  In this example, we will wait a bit of time to let inrush currents settle,
		// and then change DIVSEL from /4 to /2.  This is only an example.  The amount of
		// time you need to wait depends on the power supply feeding the DSP (i.e., how much
		// voltage droop occurs due to the inrush currents, and how long it takes the
		// voltage regulators to recover).
		SysCtrlRegs.PLLSTS.bit.MCLKOFF = 0;				// Enable missing clock detect circuitry
		DelayUs(20/2);									// Wait 20 us (just an example).  Remember we're running
														// at half-speed here, so divide function argument by 2.
		SysCtrlRegs.PLLSTS.bit.DIVSEL = 0x2;			// Change to /2 mode
	}
	else
	{													// PLL is running in limp mode
	// User should replace the below with a call to an appropriate function,
	// for example shutdown the system (since something is very wrong!).
		asm(" ESTOP0");
	}

	//--- Configure the clocks
	SysCtrlRegs.HISPCP.all = 0x0000;		// Hi-speed periph clock prescaler, HSPCLK=SYSCLKOUT/1
	SysCtrlRegs.LOSPCP.all = 0x0002;		// Lo-speed periph clock prescaler, LOSPCLK=SYSCLKOUT/4

	SysCtrlRegs.PCLKCR3.bit.GPIOINENCLK = 1;	// GPIO input module is clocked
	SysCtrlRegs.PCLKCR3.bit.XINTFENCLK = 1;		// XINTF module is clocked
	SysCtrlRegs.PCLKCR3.bit.DMAENCLK = 1;		// SYSCLKOUT to DMA enabled
	SysCtrlRegs.PCLKCR3.bit.CPUTIMER2ENCLK = 1;	// SYSCLKOUT to CPU Timer2 enabled
	SysCtrlRegs.PCLKCR3.bit.CPUTIMER1ENCLK = 1;	// SYSCLKOUT to CPU Timer1 enabled
	SysCtrlRegs.PCLKCR3.bit.CPUTIMER0ENCLK = 1;	// SYSCLKOUT to CPU Timer0 enabled

	SysCtrlRegs.PCLKCR1.bit.EQEP2ENCLK = 1;		// SYSCLKOUT to eQEP2 enabled
	SysCtrlRegs.PCLKCR1.bit.EQEP1ENCLK = 1;		// SYSCLKOUT to eQEP1 enabled
	SysCtrlRegs.PCLKCR1.bit.ECAP6ENCLK = 1;		// SYSCLKOUT to eCAP6 enabled
	SysCtrlRegs.PCLKCR1.bit.ECAP5ENCLK = 1;		// SYSCLKOUT to eCAP5 enabled
	SysCtrlRegs.PCLKCR1.bit.ECAP4ENCLK = 1;		// SYSCLKOUT to eCAP4 enabled
	SysCtrlRegs.PCLKCR1.bit.ECAP3ENCLK = 1;		// SYSCLKOUT to eCAP3 enabled
	SysCtrlRegs.PCLKCR1.bit.ECAP2ENCLK = 1;		// SYSCLKOUT to eCAP2 enabled
	SysCtrlRegs.PCLKCR1.bit.ECAP1ENCLK = 1;		// SYSCLKOUT to eCAP1 enabled
	SysCtrlRegs.PCLKCR1.bit.EPWM6ENCLK = 1;		// SYSCLKOUT to ePWM6 enabled
	SysCtrlRegs.PCLKCR1.bit.EPWM5ENCLK = 1;		// SYSCLKOUT to ePWM5 enabled
	SysCtrlRegs.PCLKCR1.bit.EPWM4ENCLK = 1;		// SYSCLKOUT to ePWM4 enabled
	SysCtrlRegs.PCLKCR1.bit.EPWM3ENCLK = 1;		// SYSCLKOUT to ePWM3 enabled
	SysCtrlRegs.PCLKCR1.bit.EPWM2ENCLK = 1;		// SYSCLKOUT to ePWM2 enabled
	SysCtrlRegs.PCLKCR1.bit.EPWM1ENCLK = 1;		// SYSCLKOUT to ePWM1 enabled

	SysCtrlRegs.PCLKCR0.bit.ECANBENCLK = 1;		// SYSCLKOUT/2 to eCAN-B enabled
	SysCtrlRegs.PCLKCR0.bit.ECANAENCLK = 1;		// SYSCLKOUT/2 to eCAN-A enabled
	SysCtrlRegs.PCLKCR0.bit.MCBSPAENCLK = 1;	// LSPCLK to McBSP-A enabled
	SysCtrlRegs.PCLKCR0.bit.MCBSPBENCLK = 1;	// LSPCLK to McBSP-B enabled
	SysCtrlRegs.PCLKCR0.bit.SCIBENCLK = 1;		// LSPCLK to SCI-B enabled
	SysCtrlRegs.PCLKCR0.bit.SCIAENCLK = 1;		// LSPCLK to SCI-A enabled
	SysCtrlRegs.PCLKCR0.bit.SPIAENCLK = 1;		// LSPCLK to SPI-A enabled
	SysCtrlRegs.PCLKCR0.bit.SCICENCLK = 1;		// LSPCLK to SCI-C enabled
	SysCtrlRegs.PCLKCR0.bit.I2CAENCLK = 1;		// LSPCLK to I2C-A enabled
	SysCtrlRegs.PCLKCR0.bit.ADCENCLK = 1;		// HSPCLK to ADC enabled

	// The PCLKCR0.TBCLKSYNC bit is handled in the InitEPwm() function since
	// it affects synchronization of the ePWM counters.

	//--- Configure the low-power modes
	SysCtrlRegs.LPMCR0.all = 0x00FC;		// LPMCR0 set to default value

	//--- Finish up
	asm(" EDIS");							// Disable EALLOW protected register access
}

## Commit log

2025-10-09 Actualizacion - Varios
    Se agregan esquematicos de cada pcb, programa, readme de cada carpeta.
    [AC_Current_Voltage_Measurement.SchDoc, AC_Output.PcbDoc, AC_Output.PrjPcb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]
2025-11-09 Nuevo - Agregado de data logger para el dsp
    Se agrega la posibilidad de utilizar un data logger en variables que se requieran visualizar. Puede ser que dicho data logger no esté optimizado de la mejor manera para que sea rapido en la ISR. En g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
2025-11-10 Nuevo - Agregado de programa para manejar fuente de Tension

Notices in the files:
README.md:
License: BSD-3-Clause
